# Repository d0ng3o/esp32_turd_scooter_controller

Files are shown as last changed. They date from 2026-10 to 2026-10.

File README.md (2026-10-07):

# Scooter control board

A standalone replacement control board for a **decommissioned Bird One #590AE**
shared e-scooter (the operator went bankrupt), built around a **Seeed XIAO
ESP32-C3**.

> ⚠️ **Safety-critical, experimental, unofficial.** This board controls a
> vehicle's motor, throttle, and braking behavior. It is provided **as-is, with
> no warranty**, is not certified by anyone, and is not affiliated with or
> endorsed by Bird. Build and ride at your own risk — read
> **[DISCLAIMER.md](DISCLAIMER.md)** first.

The project has two halves:

1. **Reverse-engineering** the scooter's one-wire bus between the original
   control board and the Lishui motor controller — captured and documented so
   the controller can be driven directly.
2. A **custom KiCad control board** that replaces the dead original: same
   harness connector, same bus protocol, plus throttle/brake sensing, pack
   voltage, a buzzer, an addressable status LED, an on-board IMU for
   wake-on-motion, and an OLED display.

## Repository layout

```
.
├── PROTOCOL.md                 the reverse-engineered one-wire bus protocol
├── captures/                   raw bus captures backing PROTOCOL.md
├── esp32-scooter-schematic.html  interactive overview of the board
│
├── scooter_master.py           drive the motor controller as the bus master
├── pi_sniff.py                 passive ride logger (Raspberry Pi, RX-only)
├── bus_experiment.py           scripted bring-up probes
├── bus_listen_poll.py          poll at 50 Hz and log non-echo bytes
├── bus_soak.py                 long idle soak to catch slow telemetry fields
├── install_logger.sh           one-shot Pi logger installer
├── pi-scooter-logger.service   systemd unit for the Pi logger
│
└── kicad/                      the hardware — see kicad/README.md
```

## The bus, briefly

Native **3.3 V open-drain half-duplex UART at 115200**. The control board is the
master: it polls the controller at 50 Hz with a colon-framed packet
(`':' TYPE LEN DATA[LEN] CHK CR LF`, `CHK` = XOR of the header+data) carrying the
throttle and light flags, and the controller answers with telemetry. Full frame
types, flags and field map are in **[PROTOCOL.md](PROTOCOL.md)**; it was all
confirmed on hardware (the PC drove the motor across the full throttle range).

## The hardware

The KiCad 10 design lives in **[kicad/](kicad/)** — see
[kicad/README.md](kicad/README.md) for the board overview,
[kicad/board/BOM.md](kicad/board/BOM.md) for the parts and full design
rationale, and [kicad/board/LAYOUT.md](kicad/board/LAYOUT.md) for the layout
playbook. The board is DRC-clean; bare boards and parts have been ordered.

## Status

- ✅ Bus protocol reverse-engineered and documented.
- ✅ Host/Pi tooling to drive and log the bus.
- ✅ Control board schematic + PCB complete, DRC-clean, ordered.
- ⬜ ESP32-C3 firmware — not in this repo yet.

## Note

The Python here is **host-side** tooling (PC / Raspberry Pi) used to
reverse-engineer and exercise the bus. It connects to the scooter via a USB
serial adapter (`scooter_master.py`, bench scripts) or a Pi UART (`pi_sniff.py`).
The firmware that will run on the XIAO itself is separate and not committed yet.

## License

This project is **free/libre and strong-copyleft** — multi-licensed by component,
with each layer under a **share-alike** license. Anyone who copies, modifies, or
builds on it **must release their version under the same license** (no closed or
proprietary forks):

| Component | Files | License |
|---|---|---|
| Code / firmware / scripts | `*.py`, `*.sh`, `*.service` | **GPL-3.0-or-later** — [`LICENSE`](LICENSE) |
| Hardware design (original) | `kicad/board/`, original symbols/footprints | **CERN-OHL-S-2.0** — [`LICENSE-HARDWARE.txt`](LICENSE-HARDWARE.txt) |
| Documentation | `*.md`, BOMs, `esp32-scooter-schematic.html` | **CC-BY-SA-4.0** — [`LICENSE-DOCS.txt`](LICENSE-DOCS.txt) |

Copyright 2026 Taavi Laadung.

**Exception:** the vendor-sourced symbols, footprints, and 3D models under
`kicad/lcsc/` are **not** covered by the above and keep their original
LCSC/EasyEDA/manufacturer terms — see [`kicad/lcsc/README.md`](kicad/lcsc/README.md).

**CERN-OHL-S v2 notice (hardware):** *Copyright 2026 Taavi Laadung. This source
describes Open Hardware and is licensed under the CERN-OHL-S v2. You may
redistribute and modify this source and make products using it under the terms of
the CERN-OHL-S v2 (https://ohwr.org/cern_ohl_s_v2.txt). This source is distributed
WITHOUT ANY EXPRESS OR IMPLIED WARRANTY, INCLUDING OF MERCHANTABILITY,
SATISFACTORY QUALITY AND FITNESS FOR A PARTICULAR PURPOSE. Please see the
CERN-OHL-S v2 for applicable conditions. Source location:*
`https://github.com/d0ng3o/esp32_turd_scooter_controller` *(CERN-OHL-S requires the
source location to be conveyed and, where practicable, kept visible on the product
itself).*

## Disclaimer

See **[DISCLAIMER.md](DISCLAIMER.md)** for the full safety warning and the
"no affiliation" / reverse-engineering notices. In short: this is an
experimental, uncertified board that controls a vehicle — **build and ride at
your own risk**, and check your local road-traffic laws before using it.

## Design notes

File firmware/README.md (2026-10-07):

# Scooter controller firmware (ESP-IDF)



Firmware for the on-board **Seeed XIAO ESP32-C3 (U3)**. It reads the rider's
throttle and brake, drives the Lishui motor controller over the scooter's
one-wire bus (see [`../PROTOCOL.md`](../PROTOCOL.md)), and enforces the safety
interlocks. Built with **ESP-IDF v5.2+**.

> ⚠️ Safety-critical. Read [`../DISCLAIMER.md`](../DISCLAIMER.md). The default
> state is always **throttle 0**; any lost bus link or engaged brake forces it.

## Status

| Area | State |
|---|---|
| One-wire open-drain UART bus (colon protocol, echo-filtered, 50 Hz poll + status decode) | ✅ |
| Throttle/brake ADC, filtering, mapping | ✅ (placeholder calibration) |
| Ride state machine + failsafes (brake→0, link-loss, lock) | ✅ |
| Kick-to-start | enforced by the motor controller (PROTOCOL.md §6.2) — not duplicated in firmware |
| Ride-feel shaping (throttle cap, curve, soft-start) | ✅ |
| NVS config store (all tunables, web-UI-ready) | ✅ |
| Configurable lights (headlight auto/on/off/manual, experimental brake strobe) | ✅ |
| Gestures: unlock (brake+triple-blip) / config-mode (brake+full 20 s) | ✅ |
| Lock/security: boots locked, auto-lock, motion alarm | ✅ |
| IMU (LSM6DS3TR-C) wake-on-motion + idle keep-alive | ✅ |
| Deep sleep to conserve the pack (two-stage idle; lights cleared before sleep) | ✅ |
| WiFi config portal + web UI + OTA (brake+20 s gesture) | ✅ |
| Pack-voltage sensing (ADC2, WiFi-gated) | ✅ |
| Guided throttle/brake calibration (web UI) | ✅ |
| OLED telemetry (SSD1309, LVGL) | ✅ |

**Feature-complete** against the plan. Remaining work is hardware validation
(the open-drain single-wire UART and the IMU register sequence want a scope).

## Layout

```
firmware/
├── CMakeLists.txt, sdkconfig.defaults, partitions.csv   # project + dual-OTA flash map
└── main/
    ├── board.h        pin map + tunables (edit here)
    ├── protocol.[ch]  frame build/decode + XOR checksum (ports PROTOCOL.md)
    ├── bus.[ch]       open-drain UART, echo filter, poll loop, telemetry
    ├── inputs.[ch]    throttle/brake ADC + mapping
    ├── control.[ch]   ride state machine + safety interlocks
    ├── buzzer.[ch]    LEDC tones
    ├── status_led.[ch] WS2812 (led_strip)
    └── app_main.c     init + real-time ride loop
```

## Building (manual, from scratch)

Built and verified with **ESP-IDF v5.4** (v5.2+ should work). The only external
dependency is the managed component `espressif/led_strip`, fetched automatically
on the first build.

### 1. Install ESP-IDF (one-time)

**Windows** (PowerShell):
```powershell
git clone -b release/v5.4 --recursive https://github.com/espressif/esp-idf.git "$env:USERPROFILE\esp\esp-idf"
& "$env:USERPROFILE\esp\esp-idf\install.ps1" esp32c3
```

**Linux / macOS**:
```bash
git clone -b release/v5.4 --recursive https://github.com/espressif/esp-idf.git ~/esp/esp-idf
~/esp/esp-idf/install.sh esp32c3
```

(Alternatively use the official VS Code **ESP-IDF extension** or the Windows
installer — both wrap the same steps.)

### 2. Export the environment (each new shell)

This sets `IDF_PATH` and puts `idf.py` + the RISC-V toolchain on `PATH`. It does
**not** persist, so run it in every new terminal:

- **Windows** (PowerShell): `. "$env:USERPROFILE\esp\esp-idf\export.ps1"`
- **Linux / macOS**: `. ~/esp/esp-idf/export.sh`

### 3. Build

```bash
cd firmware
idf.py set-target esp32c3     # first time only (creates sdkconfig from sdkconfig.defaults)
idf.py build
```

The first build compiles all of ESP-IDF (several minutes); later builds are
incremental. Output: `build/turd_scooter_fw.bin` (~243 KB).

One-liner for a fresh Windows shell:
```powershell
. "$env:USERPROFILE\esp\esp-idf\export.ps1"; cd firmware; idf.py build
```

### 4. Flash & monitor

Connect the XIAO over USB-C (native USB-Serial-JTAG), then:
```bash
idf.py -p <PORT> flash monitor      # e.g. -p COM7 (Windows) or -p /dev/ttyACM0 (Linux)
```
Exit the monitor with **Ctrl-]**. Console/log runs on USB-Serial-JTAG, so
**UART1 (GPIO20/21) stays free for the motor bus** and flashing never fights the
bus link.

### Housekeeping

- `idf.py fullclean` — wipe `build/`.
- `idf.py menuconfig` — edit settings interactively (defaults come from
  `sdkconfig.defaults`; the generated `sdkconfig` and `build/` are git-ignored).
- `idf.py size` — flash/RAM usage breakdown.

## Pin map (XIAO silk → GPIO)

| Silk | GPIO | Function |
|---|---|---|
| D1 | 3 | brake (ADC1_CH3) |
| D2 | 4 | throttle (ADC1_CH4) |
| D6 | 21 | bus TX (open-drain) |
| D7 | 20 | bus RX (tied to D6) |
| D8 | 8 | WS2812 status LED |
| D9 | 9 | buzzer |

(D0 IMU-INT, D3 pack sense, D4/D5 I²C, D10 expansion are wired but used by later phases.)

## Bench testing (before the scooter arrives)

1. **Echo filter / loopback.** Jumper D6↔D7 (they're tied on the real board
   anyway). On boot the LED is red (no link) and you get the fault chirp — the
   poll stream transmits and its echo is stripped, so no frames mis-parse.
2. **Fake controller.** Drive the bus from a PC/USB-TTL running
   [`../scooter_master.py`](../scooter_master.py) as the *slave side*, or replay a
   `../captures/` status frame, and confirm the monitor shows the link going
   green and telemetry decoding (cross-check fields against `../pi_sniff.py`).
3. **Throttle/brake.** A pot on D2 (and D1) → watch the state machine: stopped =
   IDLE (blue), and with a simulated moving `speed>0` from the fake controller,
   release-then-apply throttle → RIDING (green); brake → BRAKING (amber), throttle 0.

## Configuration

Every tunable lives in the NVS config store and can be changed two ways, with no
rebuild — over the USB serial console, or the WiFi web portal. See the full
hardware bring-up steps in [BRINGUP.md](BRINGUP.md).

### USB serial console

Open the USB-Serial-JTAG port (`idf.py -p <PORT> monitor`, or any 115200 serial
terminal) and type at the `scooter>` prompt:

| Command | Description |
|---|---|
| `help` | list commands |
| `get` | print the full config as JSON |
| `set <key> <value>` | change one setting + save to NVS (e.g. `set throttle_cap 220`, `set headlight_mode 1`, `set ap_ssid myscooter`) |
| `status` | live telemetry: link / lock / speed / SoC / current / pack V |
| `cal start` … `cal apply` | guided calibration (`cal show` to watch, `cal cancel` to abort) |
| `wifi on` / `wifi off` | start/stop the config + OTA WiFi portal |
| `defaults` | reset config to defaults |
| `reboot` | restart |

Keys are the JSON field names printed by `get`.

### WiFi web portal (+ OTA)

Hold **brake + full throttle for 20 s** while stopped to bring up the SoftAP
(`ap_ssid`, default `turd-scooter`) at **192.168.4.1**. The page offers the same
settings as a form, a live status readout, the guided calibration, and **OTA**
firmware upload. It auto-exits after `config_timeout_s`.

### Calibration

Throttle/brake endpoints ship as placeholders in `board.h` until the real harness
is on the bench. Run `cal start` (console or web) → move both controls through
their full travel → `cal apply` to capture and save the real min/max.

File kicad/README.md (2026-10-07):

# XIAO ESP32-C3 scooter control board — KiCad

Replacement control board for a decommissioned **Bird One #590AE** e-scooter.
A **Seeed XIAO ESP32-C3** reads the throttle and brake, talks to the Lishui
motor controller over the scooter's native **one-wire 3.3 V open-drain UART**
(115200), senses pack voltage, drives a buzzer and an addressable status LED,
carries an on-board IMU for wake-on-motion, and shows telemetry on an
enclosure-mounted OLED.

Designed in **KiCad 10**.

## Layout

```
kicad/
├── board/
│   ├── scooter_board.kicad_pro   project
│   ├── scooter_board.kicad_sch   schematic  ─┐ source of truth
│   ├── scooter_board.kicad_pcb   PCB         ─┘
│   ├── BOM.md                    bill of materials + full design rationale
│   ├── LAYOUT.md                 placement/routing playbook
│   ├── fp-lib-table              points at ../lcsc (the project footprint lib)
│   └── fabrication-toolkit-options.json
├── lcsc/                         project-local parts (LCSC-sourced)
│   ├── scooter_lcsc.kicad_sym    symbols
│   ├── scooter_lcsc.pretty/      footprints (6, all used by the board)
│   └── scooter_lcsc.3dshapes/    3D models for those footprints
├── lcsc_order_bom.csv            LCSC BOM-Tool upload (5 boards, no spares)
└── poop_logo.svg                 silkscreen art
```

Open `board/scooter_board.kicad_pro` in KiCad 10. The project footprint/symbol
libraries under `lcsc/` are referenced project-relative (`${KIPRJMOD}`), so the
board opens with all parts and 3D models intact — nothing to install.

## The board at a glance

- **2-layer, ~61 × 61 mm**, GND pour both sides with stitching vias.
- **MCU:** XIAO ESP32-C3 (U3), direct-solder castellated footprint.
- **Bus:** native 3.3 V open-drain half-duplex UART — D6 (OD TX) + D7 (RX) tied,
  100 Ω series (R6) to the harness, SMF3.3A TVS (D4) at the port. **No buffer IC.**
- **Analog:** throttle / brake / pack dividers → ADCs, 3.3 V zener clamps (D1–D3).
  Pack sense is on ADC2 (WiFi-coexistence caveat — see BOM.md).
- **IMU:** on-board LSM6DS3TR-C (U2, LGA-14), I²C, INT1 → D0 for deep-sleep
  wake-on-motion.
- **Outputs:** passive buzzer (BZ1 + Q1 low-side), WS2812B status LED (LED1, +5 V).
- **Connectors:** Amphenol 98424-F52-12ALF harness (J3), JST-GH to the off-board
  OLED (J4), 1×7 expansion header (J6, carries raw PACK_41V on pin 7).

Full part list, LCSC numbers, GPIO map, Amphenol pinout and the reasoning behind
every choice are in **[board/BOM.md](board/BOM.md)**. Layout/placement guidance is
in **[board/LAYOUT.md](board/LAYOUT.md)**.

## Ordering

Every placed part carries an `LCSC` field, so the project is the source of truth
for sourcing. Two paths:

- **Bare boards + self-assembly (current plan):** export Gerbers/drill from the
  PCB editor and order the bare board; order the parts from LCSC by uploading
  `lcsc_order_bom.csv` to the [LCSC BOM Tool](https://www.lcsc.com/bom).
- **JLC assembly:** generate a BOM + CPL with the Fabrication Toolkit plugin
  (part field = `LCSC`). Note U2 (LGA) and J3 (2 mm SMD) need hot-air/assembly.

Run **DRC** before ordering. The board is DRC-clean as committed.

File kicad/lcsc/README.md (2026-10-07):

# Project parts library (vendor-sourced)

These symbols, footprints, and 3D models were imported from **LCSC / EasyEDA** and
the component manufacturers using [`easyeda2kicad`](https://github.com/uPesy/easyeda2kicad.py),
then adjusted for this board (e.g. the XIAO and Amphenol footprints).

## Licensing

Unlike the rest of this repository, the contents of this `lcsc/` directory are
**not original work** and are **not** covered by the project's CERN-OHL-S /
GPL-3.0 / CC-BY-SA licenses. They remain subject to the terms of their original
sources (LCSC / EasyEDA and the respective component manufacturers). They are
included only for convenience, so the board opens with parts and 3D bodies intact.

If you would rather not redistribute vendor models, delete the `.step` / `.wrl`
files (and, if you like, the whole library) and regenerate them from the LCSC part
numbers listed in [`../board/BOM.md`](../board/BOM.md):

```
python -m easyeda2kicad --full --lcsc_id C<number> --output scooter_lcsc
```

## Contents

- `scooter_lcsc.kicad_sym` — schematic symbols
- `scooter_lcsc.pretty/` — footprints (6, all used by the board)
- `scooter_lcsc.3dshapes/` — 3D models (`.step` + `.wrl`) for those footprints

The board also uses a few footprints from KiCad's **standard** libraries (JST-GH,
pin header) — those ship with KiCad and are not duplicated here.

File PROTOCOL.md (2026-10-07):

# Scooter One-Wire Bus Protocol

Reverse-engineered 2026-09-11 from a decommissioned shared e-scooter
(manufacturer bankrupt). This document is the reference for writing software or
firmware that replaces the original **control board** and drives the **motor
controller** directly.

- **Master** = control board (sends polls, throttle, light commands, queries)
- **Slave** = motor controller (answers polls with telemetry, holds the motor)

Everything here was confirmed on hardware: the PC drove the motor across the
full throttle range through this protocol.

---

## 1. Physical layer

| Property | Value |
|---|---|
| Bus | Single wire, half-duplex, shared by both ends |
| Idle level | High, pulled up by the controller through ~740 Ω |
| Logic | 3.3 V TTL |
| UART | 115200 baud, 8 data bits, no parity, 1 stop (8N1)  |
| Direction | Both ends transmit on the same wire; no flow ctrl  |

Because it is one wire, **every byte you transmit is also received back as an
echo.** Filter your own echo before parsing replies.

### Wiring a USB-TTL adapter as master

```
  adapter GND ------------------------------ scooter GND
  adapter RX  ------------------------------ data line        (read direct)
  adapter TX  ----[ 100 Ω ]----------------- data line        (drive through R)
```

The controller's ~740 Ω pull-up is strong. A diode-OR from TX only reaches
~1.3 V low and the controller ignores it; 1 kΩ in series gives ~1.9 V, also
ignored. **100 Ω gives a valid low and works.** The resistor limits contention
current (~30 mA for the ~2 ms the controller is replying) but leaves ~15 % of
frames colliding. For a permanent build use a real open-drain driver
(74HC07 / 74LVC07, or an FTDI adapter with TX inverted in EEPROM plus one
MOSFET) so there is no contention.

**Disconnect the original control board from the data line before driving the
bus. Never run two masters at once.**

---

## 2. Frame format (both directions)

The steady-state protocol is a colon-delimited ASCII-framed binary protocol.

```
  +------+------+------+=================+------+------+------+
  | 0x3A | TYPE | LEN  |   DATA[LEN]     | CHK  | 0x0D | 0x0A |
  +------+------+------+=================+------+------+------+
    ':'   type   len      payload          xor    CR     LF

  CHK = XOR of every byte from 0x3A through the last DATA byte (inclusive).
        i.e. XOR of  ':', TYPE, LEN, DATA[0..LEN-1].
  Total frame length = LEN + 6.
```

**Request / reply pairing:** the reply TYPE equals the request TYPE minus
`0x0A`. Poll `0x1A` → status `0x10`; serial `0x1B` → `0x11`; firmware
`0x1D` → `0x13`; `0x1E` → `0x14`.

### Checksum reference (C)

```c
uint8_t xor_chk(uint8_t type, const uint8_t *data, uint8_t len) {
    uint8_t c = 0x3A ^ type ^ len;
    for (uint8_t i = 0; i < len; i++) c ^= data[i];
    return c;
}
```

---

## 3. Master → Slave (control board → motor controller)

### 3.1 Poll `0x1A` — sent continuously at 50 Hz (every 20 ms)

This is the heartbeat. It carries throttle and light state, and every 5th poll
also requests a status reply. **The slave only stays responsive while polled.**

```
  :  1A  02  TT  FF  CK  CR LF
           |   |
           |   +-- FF = flags byte (see below)
           +------ TT = throttle 0..255  (SPEED setpoint, not torque)

  DATA[0] = throttle
  DATA[1] = flags:
        bit 3  0x08  tail light   (master keeps this set at all times)
        bit 4  0x10  request status reply this poll (set on every 5th poll)
        bit 6  0x40  headlight    (master sets it while the wheel is moving)
```

Flag byte values seen on the wire: `0x08` (normal), `0x18` (status request),
`0x48` (headlight on), `0x58` (headlight + status request).

Examples (throttle 0, idle):

```
  status-request poll :  3A 1A 02 00 18 3A 0D 0A
  normal poll         :  3A 1A 02 00 08 2A 0D 0A
```

**Cadence pattern:** 4 normal polls then 1 status-request poll, repeating →
50 polls/s, 10 status replies/s.

### 3.2 Serial-number query `0x1B` — DATA = `"SN"` (0x53 0x4E)

```
  :  1B  02  53 4E  3E  CR LF        ->  slave replies 0x11
```
Answered any time.

### 3.3 Firmware query `0x1D` — DATA = `"FW"` (0x46 0x57)

```
  :  1D  02  46 57  <ck>  CR LF      ->  slave replies 0x13
```
**Only answered once, shortly after the controller's own power-up.** Later
queries get no reply.

### 3.4 Boot one-shots (original board sent these once at startup)

| TYPE | DATA | Reply | Notes |
|---|---|---|---|
| 0x1E | `20 10` | `0x14 20 10` | echoed back |
| 0x1F | `02 F4` | none | no observable effect |
| 0x20 | `00 87` | none | no observable effect |

These appear **unnecessary** to drive the motor; the controller runs on a bare
poll stream. Kept here for completeness.

---

## 4. Slave → Master (motor controller → control board)

### 4.1 Boot banner (unsolicited)

About 5 s after the controller powers up it sends, once:

```
  :  1D  "READY"  CR LF        =  3A 1D 52 45 41 44 59 0D 0A
```
(Note: this uses TYPE 0x1D as a one-off banner; it is not a reply to anything.)

### 4.2 Status `0x10` — 21-byte reply to a status-request poll, ~10 Hz

**This is the telemetry frame.** All 16-bit fields are **big-endian**.

```
  :  10  15  [ 21 data bytes ]  CK  CR LF

  offset  name          type    meaning
  ------  ------------  ------  --------------------------------------------
   0- 1   temp1         u16 BE  controller/FET TEMPERATURE (raw, scale TBD).
                                ~2960 cool; rises with ride time, holds at idle;
                                proven thermal by ride (corr 0.93 with time, not
                                current) + flat over a 1 h idle soak.
   2- 3   temp2         u16 BE  second TEMPERATURE (motor?). Same behaviour,
                                smaller rise (~2960->2980 over a ride).
   4- 5   current       u16 BE  battery current, 0.01 A units. 16-bit CONFIRMED:
                                reached ~20 A (b4=0x07) under real road load.
                                (idle ~0.03 A; ~20 A under load)
   6      (zero)        u8      always 0
   7      charge_A      u8      charge current, 0.01 A units (max 2.55 A)
                                (0 with charger unplugged; ~1.6 A CC tapering to
                                ~0.2 A CV while charging)
   8- 9   soc           u16 BE  state of charge, percent. b8 (high) always 0
                                in all data; effectively a single byte here.
  10      status_bit    u8      0 or 1; a status bit (meaning unresolved,
                                leans toward 'moving')
  11      (zero)        u8      always 0
  12      speed         u8      wheel speed reading (0..~156 powered cap;
                                seen up to 165 coasting/downhill past the limit)
  13      flag13        u8      constant 0x0E (unknown)
  14      (zero)        u8      always 0
  15-17   odometer      u24 BE  wheel-revolution counter (1 count ≈ 1 rev)
  18      state_flags   u8      motion-state bit flags (NOT constant):
                                0x01 base/ready (always set), +0x02 at standstill,
                                +0x04 at high speed near the limiter, 0x0b rare
  19      flag19        u8      constant 0x10 (unknown)
  20      margin        u8      load-sensitive voltage margin (NOT temperature).
                                ~105 idle-no-load; -33 when headlight on; sags
                                under motor load; slowly declines as pack depletes;
                                climbs while charging. Bus/back-EMF headroom.
```

Worked example (idle, off-charger):

```
  3A 10 15 0B A4 0B A4 00 04 00 00 00 64 00 00 00 0E 00 15 87 E7 01 10 63 56 0D 0A
           \___/ \___/ \___/ ^  ^  \___/ ^  ^  ^  ^  ^  \______/ ^  ^  ^  ck
            2980  2980  0.04A |  |   100 |  |  |  |  |   1411047  |  | 0x63
            v1    v2    curr  0 chg soc  1  0 spd 0e 0  odo rev   1 0x10
```

Both current fields (offsets 4-5 and 7) are in **0.01 A units**. Confirmed by
the charge field: it caps at 2.55 A as a single byte and read ~1.6 A tapering
to ~0.2 A on the charger, matching a ~2 A scooter charger; at a 0.1 A scale it
would imply an impossible ~16 A charger.

### 4.3 Serial reply `0x11` — DATA = ASCII identifiers

```
  "RF02P192150317 RF01L192001491"
```
Two space-separated IDs (controller and, likely, a second board).

### 4.4 Firmware reply `0x13` — DATA = ASCII version string

```
  "C2.12-P0.2/3.3-B2.0/2.2"
```
Sent only once after boot (see 3.3).

### 4.5 Echo reply `0x14` — DATA = `20 10`

Reply to `0x1E`.

---

## 5. Sequencing / timing

### 5.1 Cold boot (as the original board did it)

```
  t=0 s     controller powers up
  t≈+5 s    controller sends  : 1D "READY" CR LF
  t≈+16 s   board begins probing with legacy framings, unanswered:
              - Xiaomi M365  (header 55 AA, addr 0x20)
              - unknown      (header BE EF)
              - Ninebot ES   (header 5A A5, src 0x21/0x3E dst 0x20)
            board sends SN/FW queries and the 1E/1F/20 one-shots (once)
  then      board settles into the colon protocol: 50 Hz polls forever
```

The legacy-probe phase is the board hunting for a known controller before
falling back to this vendor's own colon protocol. **You do not need to
reproduce it.** A bare 50 Hz poll stream is accepted, including after the
controller has been running a while.

### 5.2 Steady state

```
  poll 20 ms apart, pattern:  N N N N S  N N N N S ...   (S = status request)
  → 50 polls/s, 10 status frames/s
  Reply latency: status frame arrives within ~1 poll of the request.
```

### 5.3 Robustness observed

- **Poll gap:** stop polling for seconds, resume — status resumes on the next
  status-request poll. No re-handshake, no watchdog reset seen.
- **Peer drop/reconnect:** the controller resumes replying within ~200 ms of
  hearing polls again. It does **not** re-run the boot banner or probes.
- **Single-frame glitches:** occasional lone status frames carry a garbled
  field but still pass the checksum. **Filter single-frame outliers** (e.g. the
  odometer jumping and snapping back) in your reader.

---

## 6. Control behavior (for the firmware author)

### 6.1 Throttle is a SPEED setpoint, linear

Measured map (free-spinning wheel, 222 mm, ~25 km/h limit):

```
  throttle:    76   102   127   153   178   204   229   255
  speed rdg:   54    68    82    97   111   126   140   156
  free-I(A):  0.4   0.5   0.6   0.8   0.8   0.9   1.1   1.1
```

(Free-spin battery current, 0.01 A units. Real riding load draws more.)

Fit: `speed ≈ 0.56 × throttle + 11`, saturating at 156 (the 25 km/h limiter)
at throttle 255. Because it is a speed target, a lightly loaded wheel holds a
steady speed rather than running away.

Speed reading → real speed: at reading 156 the wheel turns ~10 rev/s. With a
0.70 m circumference that is ~7 m/s ≈ **25 km/h**, so the speed byte is
≈ 0.16 km/h per count (hypothesis: tenths of mph).

Odometer: **1 count ≈ 1 wheel revolution ≈ 0.70 m.** Not persisted by the
controller alone — it reset to its session-start value after a power cycle, so
the original board likely wrote it back.

### 6.2 Kick-to-start (safety interlock)

The motor engages **only if both** are true:

1. the wheel is already turning (any low speed reading works), and
2. the throttle **rises from idle** *after* motion is established
   (~0.3 s of confirmed motion first).

Throttle applied while stationary, or applied before/at the instant of the
push, is ignored until you release and re-apply. Design your throttle logic to
release to 0 and re-assert once the wheel is moving.

### 6.3 Brake

The lever is analog on the scooter but the board sends **no brake field**.
Instead, when the brake crosses ~half travel the master forces the **throttle
byte to 0x00** for as long as it is held. Braking is therefore "command speed
0"; there is no separate brake signal to the controller and no brake-light
change on the bus (the tail light is simply always on via flag 0x08).

Replicate this: read your brake input and clamp the throttle byte to 0 above
threshold.

### 6.4 Headlight

Master sets poll flag **0x40** while the controller reports speed > 0, and
clears it ~0.5 s after the wheel stops. The tail light is the always-on
flag 0x08. Both are commands from master to slave.

**The controller latches the last commanded light state when polling stops.** It
does not auto-clear the lights when the poll stream ends — it holds whatever was
last sent. So a master that is about to stop polling (e.g. firmware entering
deep sleep) must first send a poll with the light flags **cleared** (no 0x08 /
0x40) to turn the lights off; otherwise they stay lit on the dormant controller.
On resuming polling, normal flags turn them back on.

### 6.5 Power / charger interlock

- The controller drives the motor **only with battery power present.** With the
  battery disconnected it can boot on charger standby but reports 0.00 A and will
  not drive.
- To **ride**, the charger must be **unplugged** (a connected charger did not
  block motion in normal operation, but after a full battery disconnect the unit
  would only boot with the charger in — a BMS quirk; unplug it once running).

---

## 7. Minimal master loop (pseudocode)

```
open serial: 115200 8N1, COM4
n = 0
every 20 ms:
    n += 1
    flags = 0x08
    if n % 5 == 0:      flags |= 0x10        # request status
    if wheel_moving:    flags |= 0x40        # headlight
    throttle = brake_active ? 0 : throttle_cmd
    send_frame(0x1A, [throttle, flags])

on receive, after stripping our own echo:
    parse frames ':' TYPE LEN DATA CHK CR LF
    verify CHK (XOR)
    if TYPE == 0x10 and LEN == 21:  decode_status(DATA)   # see §4.2
    if TYPE == 0x11:  serial string
    if TYPE == 0x13:  firmware string
```

A reference implementation is in `scooter_master.py` (interactive, with logging
and a wiring self-check). Raw and decoded captures are under `captures/` and
`logs/`.

---

## 8. Open items

| Item | Status |
|---|---|
| `temp1`/`temp2` scale | Confirmed temperatures; raw→°C needs a thermometer |
| `b20` margin scale | Load-sensitive voltage margin; scale unmapped |
| Raw pack voltage | NOT transmitted; only SoC is sent |
| `flag13` (0x0E), `flag19` (0x10) | Constant; meaning unknown |
| Speed-byte real-world unit  | ≈0.16 km/h/count (hypothesis, tenths of mph) |
| Boot one-shots 0x1F / 0x20  | No observed effect; likely unnecessary |
| Odometer persistence | Not saved by controller alone |

`temp1`/`temp2` are confirmed temperatures (ride isolates them from load); to
calibrate raw→°C, hold a thermometer on the controller/motor while logging.
Pack voltage is not on the bus, only SoC.

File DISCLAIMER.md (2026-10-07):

# Disclaimer

## Safety

This is an **experimental, unofficial, hobbyist** replacement control board for
an electric scooter. It directly controls a vehicle's **motor, throttle response,
and related behavior** — a safety-critical function.

- It is provided **AS IS, WITHOUT WARRANTY OF ANY KIND**, as stated in the
  project licenses.
- It has **not** been tested, certified, or approved by any manufacturer,
  regulator, or road-safety authority.
- Building, assembling, installing, and riding anything based on these files is
  **entirely at your own risk**. You are responsible for your own safety and the
  safety of others around you.
- A fault in the hardware, firmware, or assembly could cause **sudden
  acceleration, loss of braking assistance, fire, or other dangerous failures**.
- Modifying an e-scooter may void warranties, violate local vehicle/road-traffic
  regulations, and affect insurance. **Check your local laws** before using it on
  public roads, paths, or anywhere else.

If you are not able to evaluate and knowingly accept these risks yourself, **do
not build or use this project.**

## No affiliation

This is an independent project. It is **not affiliated with, authorized by, or
endorsed by Bird**, Lishui, Seeed Studio, or any other company whose products or
trademarks are referenced. All product names and trademarks are the property of
their respective owners and are used here only for factual, descriptive
(interoperability) purposes — i.e. to state what hardware this project is
compatible with.

## Reverse engineering

The bus protocol documented here was obtained by **observing signals on hardware
that was legally acquired**, for the purpose of **interoperability** (building a
compatible replacement). No software was decompiled and no technical protection
measure (DRM/encryption) was circumvented.

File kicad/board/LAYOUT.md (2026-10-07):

# Scooter control board — PCB layout notes

Things to remember when placing and routing `scooter_board.kicad_pcb`.
Schematic-level placement hints (decoupling caps, IMU_INT) are also written as
text notes on the sheet itself. This file is the broader layout playbook.

The board has **no regulator and no high-current path** (buzzer ~90 mA is the
peak load), so there are **no thermal concerns** — this is a signal-integrity
and mechanical layout, not a power layout.

---

## 1. The big one: XIAO antenna keep-out (matters for WiFi/BLE)

The XIAO ESP32-C3 has a **PCB chip antenna at the USB-C end** of the module.
The module sits on sockets *above* this carrier board, so **copper on the
carrier under/around the antenna will detune it** and wreck WiFi range — which
you need for the config/OTA mode.

- Leave a **ground/copper keep-out** on *all layers* under the antenna end of
  the XIAO (roughly the last ~10 mm at the USB-C side). No pour, no traces there.
- Orient the XIAO so its antenna end points **off the board edge / toward open
  space**, not into the middle of the ground pour or toward the Amphenol/harness.
- Keep the buzzer, WS2812 and bus traces away from the antenna zone too.

## 2. Ground & power

- Use a **solid ground pour/plane** (bottom layer is fine) as the reference —
  except the antenna keep-out above.
- **Bulk caps at their jobs:** C6 at the Amphenol **+5V entry**, C7 on the 3V3
  rail, C10 right at the buzzer (see §5).
- **Wide traces for the current-carrying rails:** +5V feeds the XIAO regulator,
  buzzer and WS2812 — give it a fat trace/pour from the Amphenol. +3V3 similar.
- One clean ground: tie the analog return (divider/ADC grounds) and the digital
  ground to the same plane; just keep the *buzzer's* pulsed return loop physically
  away from the analog area (see §5).

## 3. Analog (throttle / brake / pack ADCs)

These are the noise-sensitive nets — treat them gently.

- **Filter caps C1 (thr) / C2 (brk) / C3 (pack) go next to the XIAO ADC pins**,
  not next to the dividers — they buffer the ADC sample-and-hold, so they want to
  be at the pin end.
- Keep the ADC nodes (`THR_ADC`, `BRK_ADC`, `PACK_ADC`) **short and clear of the
  buzzer, WS2812 (`RGB_DIN`) and the bus** — these are ~30–50 kΩ-impedance lines
  and pick up noise easily.
- The clamp zeners **D1/D2/D3 sit on the ADC nodes** near the XIAO.
- ADC pin map (for silkscreen/sanity): **D1 = brake, D2 = throttle, D3 = pack**
  (pack is ADC2 — see BOM's WiFi note).

## 4. One-wire bus

- **Put the TVS (D4) right at the Amphenol bus pin (J3.8)** so it clamps ESD at
  the port, before the signal reaches R6 and the XIAO.
- R6 (100 Ω) sits between the XIAO D6/D7 tie-point and the bus.
- The bus is only 115 kbaud, so trace length isn't critical — but still keep it
  off the analog nets.

## 5. Buzzer (BZ1 + Q1 + C10) — keep the loop tight

The buzzer is the one **noisy switching load** (2.7 kHz pulses).

- Keep the current loop **BZ1 → Q1 (drain) → C10 → back to +5V** physically
  small, with short/fat traces. That contains the switching noise locally.
- Place this whole cluster **away from the analog section (§3)** and the IMU.
- BZ1 pads **2 & 4 are mechanical fixing legs** (no net) — solder them for
  mechanical strength, but they carry nothing.
- Q1 SOT-23: G=pad1, S=pad2, D=pad3.

## 6. IMU (U2, LSM6DS3TR-C, LGA-14)

- **Leadless LGA — needs hot-air/reflow or JLC assembly**, not a hand iron.
- **C8 (VDD) and C9 (VDDIO) go hard against U2's power pins** with short ground
  returns — this is standard MEMS decoupling and matters for stable readings.
- **`IMU_INT` route short and clear of BZ/RGB/bus edges** to avoid false wakes
  (it's a high-impedance wake line). R14's own position is non-critical.
- Orientation: any orientation wakes on motion, but if you ever use tilt/axes,
  note the chip's X/Y/Z on the silkscreen relative to the scooter.

## 7. WS2812 status LED (LED1)

- **Powered at +5 V** (not 3V3). **C11 (100 nF) hugs LED1's VDD/GND.**
- Place it where the light is actually **visible** through/near the enclosure.
- `RGB_DIN` from D8 — keep it away from the analog nets.

## 8. Connectors & mechanical

- **Amphenol J3** (2 mm SMD, C239063): the harness interface. Check pin-1 /
  orientation against the mating harness before routing. This is the mechanical
  anchor to the scooter — its position is dictated by the harness, place it first.
- **XIAO (U3):** now a **single official footprint** (Seeed XIAO ESP32-C3,
  C19189385) — the two rows are at the correct fixed 17 × 2.54 mm spacing by
  construction, so no manual row-spacing to get wrong. It's the **SMD/castellated
  direct-solder** footprint (module sits flat, drag-solder the edge pads); the
  battery/debug pads on the underside are unused. Leave the **USB-C end
  accessible** for flashing/recovery, and honor the antenna keep-out (§1).
  *(If you switch to a socketed/removable through-hole footprint later, the
  antenna keep-out and USB-access notes still apply.)*
- **OLED — now off-board (J4 = JST-GH right-angle):** the 72 × 43 mm module is
  no longer on this board (it mounts to the enclosure and connects via a JST-GH
  cable). J4 is just the small 1.25 mm right-angle connector — **place it near a
  board edge with the cable exit facing the screen**, and keep its I²C legs away
  from the motor bus. No more overhang to plan around — that space is freed.
- **J6 expansion (1×7):** carries **raw PACK_41V on pin 7** — keep that pin's
  copper away from the 3V3 pins (GND on pin 6 already buffers it); the expansion
  board is responsible for its own protection.

## 9. High-voltage clearance (the 41 V pack)

- `PACK_41V` appears at the Amphenol (J3.10), R7's top pad, and J6 pin 7. It's
  **low current** (µA through the 470 k divider) so no trace-width concern, but
  keep sane **clearance** (≥ ~0.5 mm, easy at these pitches) from the low-voltage
  nets. Don't run 41 V under the XIAO or the analog dividers.
- +5 V from the harness can carry real current (XIAO + buzzer + LED) — that's the
  rail to make wide, not the 41 V sense line.

## 10. Board outline (odd shape)

- You're drawing the outline to match the original scooter PCB. Overlay a photo/
  scan on a user layer (File → Import graphics, or a bitmap on a fab layer) and
  trace `Edge.Cuts` + mounting holes to it. Place J3 (Amphenol) and the mounting
  holes to the mechanical reference first, then everything else around them.

## 11. Before ordering — checklist

- Run **DRC** (clearances, unrouted, courtyard overlaps) → clean.
- Confirm **antenna keep-out** is honored on all layers.
- Confirm XIAO **row spacing** and **USB-C access**.
- Confirm Amphenol **orientation** vs the real harness.
- Generate a **JLCPCB BOM + CPL** (Fabrication Toolkit, part field = `LCSC`);
  remember U2 (LGA) and J3 (2 mm SMD) want assembly or hot-air, and J1/J2 sockets
  are your own mechanical choice (no LCSC # assigned).
- 3D-view check for the OLED overhang and any part collisions.

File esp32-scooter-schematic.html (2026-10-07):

Rev A · Bench Reference

# XIAO Scooter Control Board

Wiring for a Seeed XIAO ESP32-C3 that replaces the dead Bird 590 control board: it reads the rider's throttle and brake, drives the Lishui motor controller over the one-wire 115200 bus, and shows telemetry on an OLED.

MCU

XIAO ESP32-C3

Bus

1-wire · 115200 8N1

Logic

3.3 V

Sensors

5 V Hall

## System schematic

41 V pack +5 V +3.3 V analog signal 1-wire data bus I2C

## Detail · the two tricky parts

Halving divider. Two equal 10 k resistors cut the sensor to half, keeping a 5 V fault off the pin and the signal in the ADC's linear band. The 100 nF cap feeds the sample-and-hold. Draw ≈ 0.25 mA per channel — negligible.

Half-duplex, one wire. Idle: buffer is Hi-Z, the controller's ~740 Ω pull-up holds the line high. A low bit: the buffer sinks ≈ 4.5 mA and the line goes low — a clean sub-0.3 V that the controller reads. No added pull-up. RX hears your own echo; filter it in software.

## Pin map

XIAO pin | GPIO | Role | Connects to
D0 | GPIO2 | ADC1_CH2 in | Throttle divider mid-node (0–2.5 V)
D1 | GPIO3 | ADC1_CH3 in | Brake divider mid-node (0–2.5 V)
D4 | GPIO6 | I2C SDA | OLED SDA
D5 | GPIO7 | I2C SCL | OLED SCL
D6 | GPIO21 | UART TX | 74LVC07 input → bus
D7 | GPIO20 | UART RX | Bus via 330 Ω
5V | — | Power in | Buck 5 V (or controller 5 V)
3V3 | — | Power out | OLED VCC
GND | — | Ground | Common with scooter GND

ADC on ADC1 (GPIO0–4) only — ADC2 is unstable on the C3. GPIO numbers are the ESP32-C3's; D-numbers are the XIAO silkscreen.

## Bill of materials

Qty | Part | Value / spec | Purpose
1 | Seeed XIAO ESP32-C3 | — | The controller / dashboard brain
4 | Resistor | 10 kΩ ¼W | Throttle + brake dividers (2 each)
2 | Capacitor | 100 nF | ADC sample filter on each mid-node
1 | 74LVC07A | hex open-drain | Bus TX driver (or 1× 2N7002 + TX invert)
2 | Resistor | 330 Ω | Series protection on RX / bus tap
1 | OLED SSD1306 | 128×64 I2C | Telemetry display
1 | Buck converter | 41 V → 5 V | Power (or tap controller's 5 V rail)
1 | Clamp diode (opt.) | BAT54 / 3.3 V zener | Transient protection on RX

## Build notes

### Power: two ways in

Cleanest is a 41 V→5 V buck off the pack into the XIAO's 5 V pin — it doesn't load the controller and leaves room for a standby cutoff later. Or tap the controller's own 5 V rail if it can spare ~100 mA for MCU + OLED + sensors. Tie all grounds together.

### Sensors need 5 V

The Hall throttle and brake are 5 V parts. Feed their VCC from the 5 V rail, run the signal back through the dividers. Calibrate idle and full-scale in software and average a few samples — the C3 ADC is a touch noisy.

### Brake logic lives in firmware

The controller has no brake field. Mirror the stock board: when the brake ADC crosses ~half travel, force the throttle byte in the 0x1A poll to 0x00. Braking is "command speed zero", nothing more on the wire.

### Why not just a bare divider on TX?

The bus is bidirectional. TX must release the line so the controller can drive its replies — that's what open-drain gives you. A plain divider or a diode can't reach a low the controller reads against its stiff 740 Ω pull-up; the 100 Ω hack proved that on the bench.

Bird 590 · Lishui LSW6G-RF-FOC · colon protocol 115200 8N1 — see PROTOCOL.md for the frame + field map

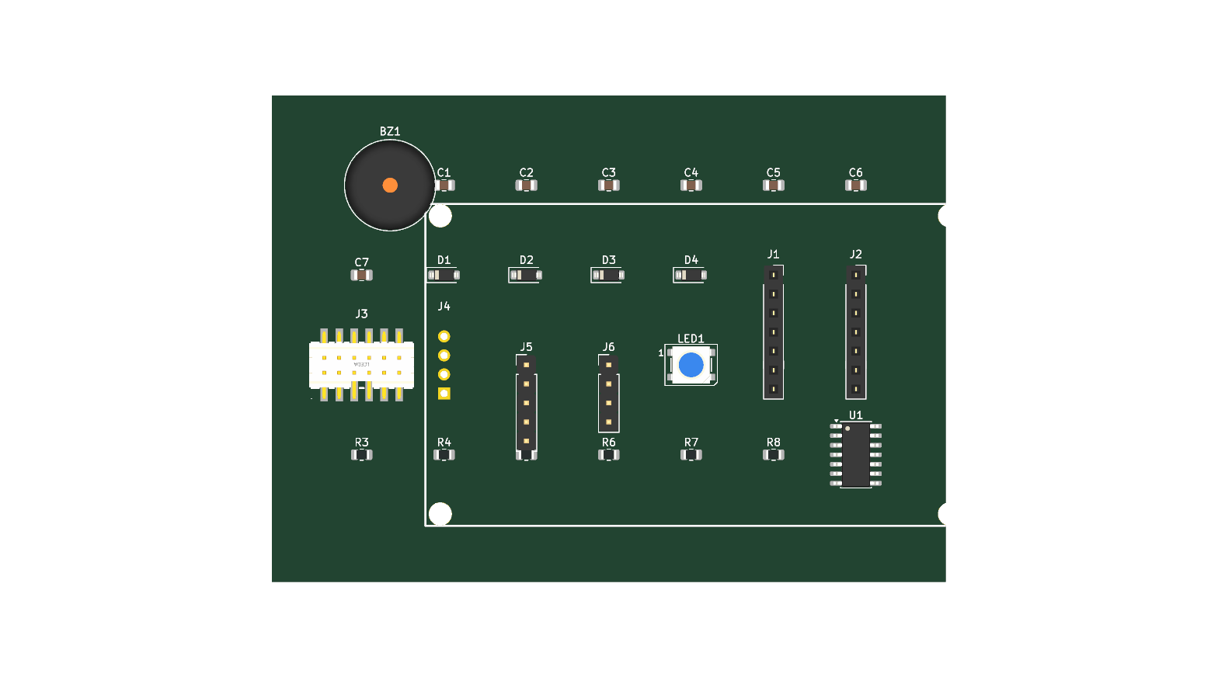
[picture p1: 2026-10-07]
kicad/board/scooter_board_render_top.png

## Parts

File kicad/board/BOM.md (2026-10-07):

# Scooter control board — BOM (LCSC / JLCPCB oriented)

Hand-solderable board: 0805 passives, SOD-123 zeners/TVS, SOT-23 MOSFET,
through-hole headers, one low-profile SMD buzzer, one 2 mm SMD Amphenol
connector. The bus is native 3.3 V open-drain UART off the XIAO (no buffer IC).
Modules (XIAO, OLED) plug into headers; IMU is on-board.

| Ref(s) | Qty | Part | Package | LCSC | Notes |
|---|-----|---|---|---|---|
| J3 | 1 | Amphenol 98424-F52-12ALF | 2×6, 2.0 mm SMD | **C239063** | confirmed; mates the scooter harness |
| R1–R4 | 4 | 100 kΩ 1% | 0805 | **C17407** | throttle + brake dividers (100k halves the 5 V signal at ~25 µA/divider). Basic |
| R6 | 1 | 100 Ω 1% | 0805 | **C17408** | bus series/protection (D6+D7 tied → R6 → bus). 100 Ω keeps the driven LOW clean (~0.4 V). Basic |
| R7 | 1 | 470 kΩ 1% | 0805 | **C17709** | pack divider top. Basic |
| R8 | 1 | 33 kΩ 1% | 0805 | **C17633** | pack divider bottom (was 30k → 33k to stay Basic; 470k/33k = 2.75 V @ 42 V). Basic |
| R9 | 1 | 1 kΩ 1% | 0805 | **C17513** | buzzer MOSFET gate series (D9→gate). Basic |
| R10 | 1 | 1 MΩ 1% | 0805 | **C17514** | buzzer MOSFET gate pulldown. **1M (not 100k): D9=GPIO9 is an ESP32-C3 boot-strap pin; a 100k pulldown drags it to ~2.3 V < V_IH at reset → download mode. 1M loads it lightly so it stays high.** Basic |
| R11, R12 | 2 | 4.7 kΩ 1% | 0805 | **C17673** | I²C pull-ups on SDA/SCL to +3V3. **Keep populated** — the on-board IMU (U2) is a bare chip with none, and the XIAO's internal pull-ups (~45k) are too weak. If your OLED module also has pull-ups they end up in parallel (~2.4k), still fine. Basic |
| R13 | 1 | 100 kΩ 1% | 0805 | **C17407** | pull-up on RGB_DIN (D8) to +3V3 — D8=GPIO8 is a boot-strap pin that would otherwise float at reset. Basic |
| R14 | 1 | 100 kΩ 1% | 0805 | **C17407** | pull-up on IMU_INT (D0/GPIO2) to +3V3 — holds the strap pin high at boot while the IMU is still initializing (INT1 hi-Z). See the IMU wake-on-motion note below. Basic |
| C1–C5, C8, C9 | 7 | 100 nF 50 V X7R | 0805 | **C49678** | ADC filters + decoupling (C8/C9 = IMU VDD/VDDIO). Basic |
| C11 | 1 | 100 nF 50 V X7R | 0805 | **C49678** | WS2812 local decoupling (+5V→GND at LED1, datasheet-recommended). Basic |
| C6, C7, C10 | 3 | 10 µF 16 V X5R | 0805 | **C1713** | C6 = 5 V bulk at Amphenol entry, C7 = 3V3 bulk, C10 = local buzzer decoupling (+5V→GND at BZ1, keeps the 2.7 kHz switching loop local). 16 V = >3× derating on the 5 V rail. Samsung CL21A106KOQNNNE, MOQ 20 |
| D1–D3 | 3 | 3.3 V Zener BZT52C3V3 | SOD-123 | **C173413** | clamp on throttle/brake/pack ADCs. Extended (no Basic in SOD-123) |
| D4 | 1 | SMF3.3A TVS (3.3 V, unidir.) | SOD-123 | **C2917875** | bus ESD/surge clamp (cathode→bus, anode→GND). ZHIDE SMF3.3A, MOQ 5 (was C283866, out of stock). Extended |
| Q1 | 1 | 2N7002 N-MOSFET (CJ) | SOT-23 | **C8545** | low-side buzzer switch (G/S/D = pad 1/2/3). Basic |
| LED1 | 1 | WS2812B-B/W (addressable RGB) | PLCC-4 5050 | **C114586** | status LED. **Powered at +5 V** (datasheet VDD 3.7–5.3 V, so 3.3 V is out of spec). The B/W variant's DIN V_IH is a fixed 2.7 V, so the ESP32's 3.3 V drives it directly — **no level shifter needed.** Extended |
| BZ1 | 1 | HYG-8503A-5027 buzzer, 5 V, passive | 8.5×8.5 mm SMD, **3.0 mm H** | **C18623826** | low-side driven by Q1; +→+5V (pad1), −→drain (pad3), pads 2/4 = fixing legs (NC). Firmware drives D9 with a ~2.7 kHz square wave. No flyback (per datasheet driving circuit). Extended |
| U2 | 1 | LSM6DS3TR-C IMU (accel + gyro) | LGA-14 2.5×3 mm | **C967633** | on-board IMU, I²C (0x6A), wake-on-motion INT1→D0. CS→3V3, SA0/SDx/SCx→GND. **Leadless — needs hot air/reflow or JLC assembly.** Extended |
| J4 | 1 | JST-GH 4-pin, right-angle SMD (SM04B-GHS-TB) | 1.25 mm, locking | **C189895** | off-board OLED link (I²C). Pinout **1=GND, 2=+3V3, 3=SCL, 4=SDA**. Locking latch = good for vibration. OLED now mounts to the enclosure, wired here via a GH cable. |
| U3 | 1 | Seeed XIAO ESP32-C3 module | LCC-14 (castellated, SMD) | **C19189385** | the MCU. **Official footprint = SMD/castellated direct-solder** (module reflows/drag-solders flat; no sockets). 14 edge pads (D0–D10, 3V3, GND, 5V) + battery/debug pads (unused). ⚠️ if you want it **socketed/removable**, ask for a through-hole footprint at the same 17×2.54 mm spacing instead. |
| J6 | 1 | 1×7 male header 2.54 mm | TH | **C2337** | expansion: D10, SDA, SCL, +5V, +3V3, GND, **PACK_41V** (pin 7, raw pack — GND on pin 6 buffers it from the 3V3 pins; expansion board handles its own protection). 1×40 breakaway, snap to length |

Off-board / sourced separately:
- **XIAO ESP32-C3** (Seeed) — now soldered as U3 (on-board), not a plug-in.
- **OLED 2.42″ SSD1309 128×64 I2C** (HS, on LCSC): white **C7466001** or blue **C7466000**. 4-pin TH 2.54 mm, pinout GND/VCC/SCL/SDA. **Now enclosure-mounted**, connected to J4 via a JST-GH cable — put a matching GH connector on the OLED's little adapter board, same pin order.
- **GH cable + OLED-side connector:** JST-GH 4-pin cable = **GHR-04V-S** housing (×2, one per end) + **SSHL-002T-P0.2** crimp contacts, or a pre-made 4-pin GH-to-GH cable. Wire it **straight-through 1:1** (GND/3V3/SCL/SDA). Keep it short (≲20 cm) for clean I²C; if long/flaky, drop R11/R12 to ~2.2 kΩ or run I²C at 100 kHz.

(The IMU is now the on-board **U2 LSM6DS3TR-C** chip — no longer a plug-in module.)

## Ordering / LCSC linkage

Every placed component now carries an **`LCSC`** schematic field with the part
number above, so the KiCad project itself is the source of truth (not just this
file). Generate a JLCPCB-ready BOM + placement file with the **Fabrication
Toolkit** plugin (bennymeg) or **File → Export → BOM** — point the tool's part
field at `LCSC`. J1/J2 are intentionally blank (your socket/mounting choice).

3D models: Q1, BZ1 and the Amphenol link portable `${KIPRJMOD}`-relative `.wrl`
models. The OLED (C7466001) has no vendor 3D model on EasyEDA, so J4 shows no
body in the 3D viewer — cosmetic only.

## Net / GPIO map

- **D0 IMU INT (deep-sleep wake) · D1 brake ADC · D2 throttle ADC · D3 pack ADC**
  - *(IMU_INT is on D0/GPIO2 — a boot-strap pin — deliberately: it's a clean digital line that a pull-up (R14) holds high at boot with no coupling to any rail. Pack was moved OFF the strap pin to D3/GPIO5, so its divider goes straight to GND with no rail coupling. See the two notes below.)*
  - *(pack is now on **ADC2** (D3/GPIO5). ADC2 on the C3 has a WiFi-coexistence caveat — reads can be blocked while the WiFi driver calibrates — but pack V is a secondary/coarse, retryable reading (bus SoC is primary), so it's fine. Throttle/brake stay on ADC1 (D2/D1).)*
  - *(all 3 strap pins are handled: D0=GPIO2 held high by R14; D8=GPIO8 by R13; D9=GPIO9 by R10=1M.)*
  - *(firmware ADC channels: brake = A1/D1, throttle = A2/D2, pack = A3/D3.)*

## IMU wake-on-motion + boot-strap (D0/GPIO2)

The IMU (U2) INT1 drives D0/GPIO2, which is both a **deep-sleep wake pin** (GPIO0–5 can wake the C3) and a **boot-strap pin**. Configure INT1 as **open-drain, active-low**, with **R14 (100 k)** pulling the line to +3V3:

- **Deep-sleep idle (no motion):** INT1 hi-Z → R14 holds the line high → *near-zero* sleep current (nothing conducts). Wake is armed on the LOW level.
- **Motion → wake:** INT1 pulls low → wakes the XIAO. On wake, firmware reads the IMU status reg to clear/deassert INT1.
- **Cold power-on:** the IMU takes ~15 ms to boot (INT1 hi-Z) while the ESP32 samples straps within ~1–3 ms → R14 holds D0 high → strap-safe.
- **At the wake instant** D0 is momentarily low, but only **GPIO9** decides run-app vs. download boot (it's untouched, internal pull-up), so the chip always boots the app; a low D0 at most affects JTAG (unused).

Firmware: `CTRL3_C` → PP_OD=1 (open-drain), H_LACTIVE=1 (active-low); route wake-up/activity IRQ to INT1; `esp_deep_sleep_enable_gpio_wakeup(BIT(2), ESP_GPIO_WAKEUP_GPIO_LOW)`. Bench-verify: sleep → tap → wakes & runs app, ~10×.

## Pack ADC (ADC2) vs. WiFi — firmware constraint

Pack sense is on **D3/GPIO5 = ADC2**. On the ESP32-C3 the WiFi driver owns ADC2 while it's running, so `adc2_get_raw()` fails/blocks **whenever WiFi is up** (not intermittent — unavailable while up, fully available while down). This is fine because the two are mutually exclusive by design:

- **Riding (normal): WiFi off** → pack ADC2 reads normally.
- **Config / OTA mode (entered by a throttle+brake gesture): WiFi on** → ADC2 blocked, but pack voltage isn't needed then, and the **controller's SoC over the bus is still available** (bus is unaffected by WiFi).

Key point: the **gesture trigger and drive-by-wire are on ADC1 (throttle D2 / brake D1)**, which WiFi never touches — so entering/exiting config mode is always reliable regardless of radio state.

Firmware rule: **read ADC2 (pack) only while the radio is stopped**; when WiFi is up, skip the pack read and fall back to the cached value or bus SoC. On exiting config mode, stop WiFi → ADC2 is available again immediately.

⚠️ If you ever run a **continuous radio during riding** (e.g. a BLE telemetry app), the radio is up while you want live pack voltage. BLE's ADC2 impact is less clear-cut than WiFi's — so in that case, use bus SoC for battery display while the radio is active and only sample ADC2 pack when it's idle. No hardware change either way.

- D4/D5 I2C (OLED + IMU) · **D6/D7 one-wire bus — tied together, D6 = open-drain TX, D7 = RX, through R6 (100 Ω) to the bus; SMF3.3A TVS on the bus**
- D8 WS2812 data · D9 buzzer · D10 expansion (J6 also carries I²C, +5V, +3V3, GND and raw PACK_41V)
- Unlock = brake + throttle gesture in firmware (no button)
- **Bus is native 3.3 V open-drain half-duplex UART** — no level shifter/buffer. Firmware: set the D6 UART TX pad to open-drain, handle self-echo. The controller's ~740 Ω pull-up provides the highs; levels are a clean 0 ↔ 3.3 V.

## Amphenol J3 pin map (CORRECTED — connector is 180° rotated from first pass)

The original assignment was mirror-imaged; each signal moved from pin N to pin
13−N. Corrected map below.

| Pin (Odd/Even) | Amphenol | Signal |
|---|---|---|
| 1 | B1 | +5V | 2 | A1 | NC |
| 3 | B2 | BRK_SIG | 4 | A2 | NC |
| 5 | B3 | GND | 6 | A3 | GND |
| 7 | B4 | GND | 8 | A4 | BUS_DATA |
| 9 | B5 | THR_SIG | 10 | A5 | PACK_41V |
| 11 | B6 | +5V | 12 | A6 | +5V |

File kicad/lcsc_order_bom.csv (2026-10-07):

Comment | Footprint | LCSC Part Number | Quantity
100nF 0805 | C_0805 | C49678 | 35
10uF 0805 16V X5R | C_0805 | C1713 | 15
100k 0805 | C_0805 | C17407 | 30
4.7k 0805 | C_0805 | C17673 | 10
470k 0805 | C_0805 | C17709 | 5
33k 0805 | C_0805 | C17633 | 5
1k 0805 | C_0805 | C17513 | 5
1M 0805 | C_0805 | C17514 | 5
100R 0805 | C_0805 | C17408 | 5
BZT52C3V3 zener SOD-123 | D_SOD-123 | C173413 | 15
SMF3.3A TVS SOD-123 | SOD-123 | C2917875 | 5
2N7002 SOT-23 | SOT-23 | C8545 | 5
WS2812B-B/W PLCC4 | LED_5050 | C114586 | 5
HYG-8503A buzzer | BUZ-SMD | C18623826 | 5
Amphenol 98424-F52-12ALF | CONN-SMD 2mm | C239063 | 5
JST-GH SM04B-GHS-TB | JST_GH RA | C189895 | 5
LSM6DS3TR-C IMU LGA-14 | LGA-14 | C967633 | 5
OLED 2.42in SSD1309 I2C white | module | C7466001 | 5

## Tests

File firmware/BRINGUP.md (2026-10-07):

# Hardware bring-up checklist

Step-by-step validation for a freshly assembled board. Work through it **in
order** — each step de-risks the next. Keep the wheel **off the ground** (on a
stand) until the very end.

> ⚠️ This controls a vehicle. Read [`../DISCLAIMER.md`](../DISCLAIMER.md). The
> firmware defaults to throttle 0; don't defeat the interlocks during bring-up.

Most checks use the USB serial console (`idf.py -p <PORT> monitor`, prompt
`scooter>`) — see [README.md](README.md#usb-serial-console).

## 0. Board power & flash
- [ ] Inspect the board; no solder bridges, correct part orientations (U2 IMU, J3 Amphenol).
- [ ] Power the XIAO over USB-C; flash: `idf.py -p <PORT> flash monitor`.
- [ ] Boot log shows config load, bus up, `ride loop started`; LED/buzzer boot chirp.
- [ ] `status` → `link=0 locked=1` (boots locked, no controller yet). Good baseline.

## 1. Status LED & buzzer
- [ ] LED shows **purple** (locked) at boot. `set led_brightness` changes it.
- [ ] Boot chirp heard. `set buzzer_enable false` silences feedback; re-enable after.

## 2. One-wire bus (the #1 risk — open-drain single wire)
- [ ] With a scope on D6/D7: confirm the 50 Hz poll frames and that **TX idles high**
      (open-drain + controller/divider pull-up), driven low cleanly (~0.4 V).
- [ ] Connect to the motor controller (original control board **disconnected** —
      never two masters). `status` → `link=1`, and `speed`/`soc`/`current` populate.
- [ ] Confirm the software echo-filter works: no garbage frames, telemetry stable
      (cross-check values against `../pi_sniff.py` on a separate logger if unsure).

## 3. Throttle & brake inputs
- [ ] `cal start` → sweep throttle fully, squeeze brake fully → `cal apply`.
- [ ] `status`/`get` reflect sane endpoints. Throttle maps 0→255 across travel.
- [ ] `brk_active_pct` threshold feels right (brake "engages" near half travel).

## 4. Ride interlocks (wheel on a stand!)
- [ ] Stationary + throttle → **no motion** (kick-to-start). Spin the wheel by hand,
      then release-and-apply throttle → motor engages. Brake → throttle forced 0.
- [ ] Yank the bus connector mid-"ride" → **fault chirp**, throttle inhibited (`link=0`).
- [ ] Soft-start feels smooth (tune `soft_start_ms`); cap via `throttle_cap`.

## 5. IMU (LSM6DS3TR-C)
- [ ] Boot log: `LSM6DS3TR-C up` (WHO_AM_I = 0x6A at I²C 0x6A). If "not found",
      check SA0→GND, SCL/SDA, and R11/R12 pull-ups.
- [ ] **Re-check the register sequence vs the datasheet** (`imu.c`) — wake bits are
      datasheet-derived, unverified on hardware.
- [ ] Idle keep-alive: at a simulated stop, small jostles keep it from auto-locking.

## 6. OLED (SSD1309 via JST-GH)
- [ ] Connect the OLED; boot log shows `OLED up` (the I²C probe detects 0x3C).
- [ ] Display shows speed / SoC / state / current / pack V. If garbled, the SSD1309
      may need a different init than the SSD1306 driver — note and adjust.

## 7. Lights (verify against the real controller)
- [ ] Headlight comes on while moving (`headlight_mode` = auto).
- [ ] **Brake strobe is experimental**: confirm toggling the tail flag (0x08) on
      brake actually blinks the tail. If it misbehaves, `set brakelight_mode 0` (steady).

## 8. Lock / security / power
- [ ] Unlock gesture: hold brake + blip throttle 3× (stopped) → unlock chirp, `locked=0`.
- [ ] Auto-lock after `auto_lock_timeout_s` idle; motion alarm when moved while locked.
- [ ] Deep sleep: idle past `auto_sleep_timeout_s` → lights clear, current drops to µA;
      a tap (IMU) wakes it, it reboots **locked**, polling resumes.

## 9. WiFi config portal + OTA
- [ ] `wifi on` (or the brake+20 s gesture) → join `ap_ssid` @ 192.168.4.1.
- [ ] Settings save; live status updates; **OTA** a new build and confirm it reboots
      into it (the spare OTA slot).

## 10. Pack voltage
- [ ] `status` pack V matches a meter on the pack (within divider tolerance). Tune the
      divider constants in `board.h` if off.

---

When all boxes are ticked, the board is ride-ready. Change settings any time via
the console or web portal — no reflash needed.

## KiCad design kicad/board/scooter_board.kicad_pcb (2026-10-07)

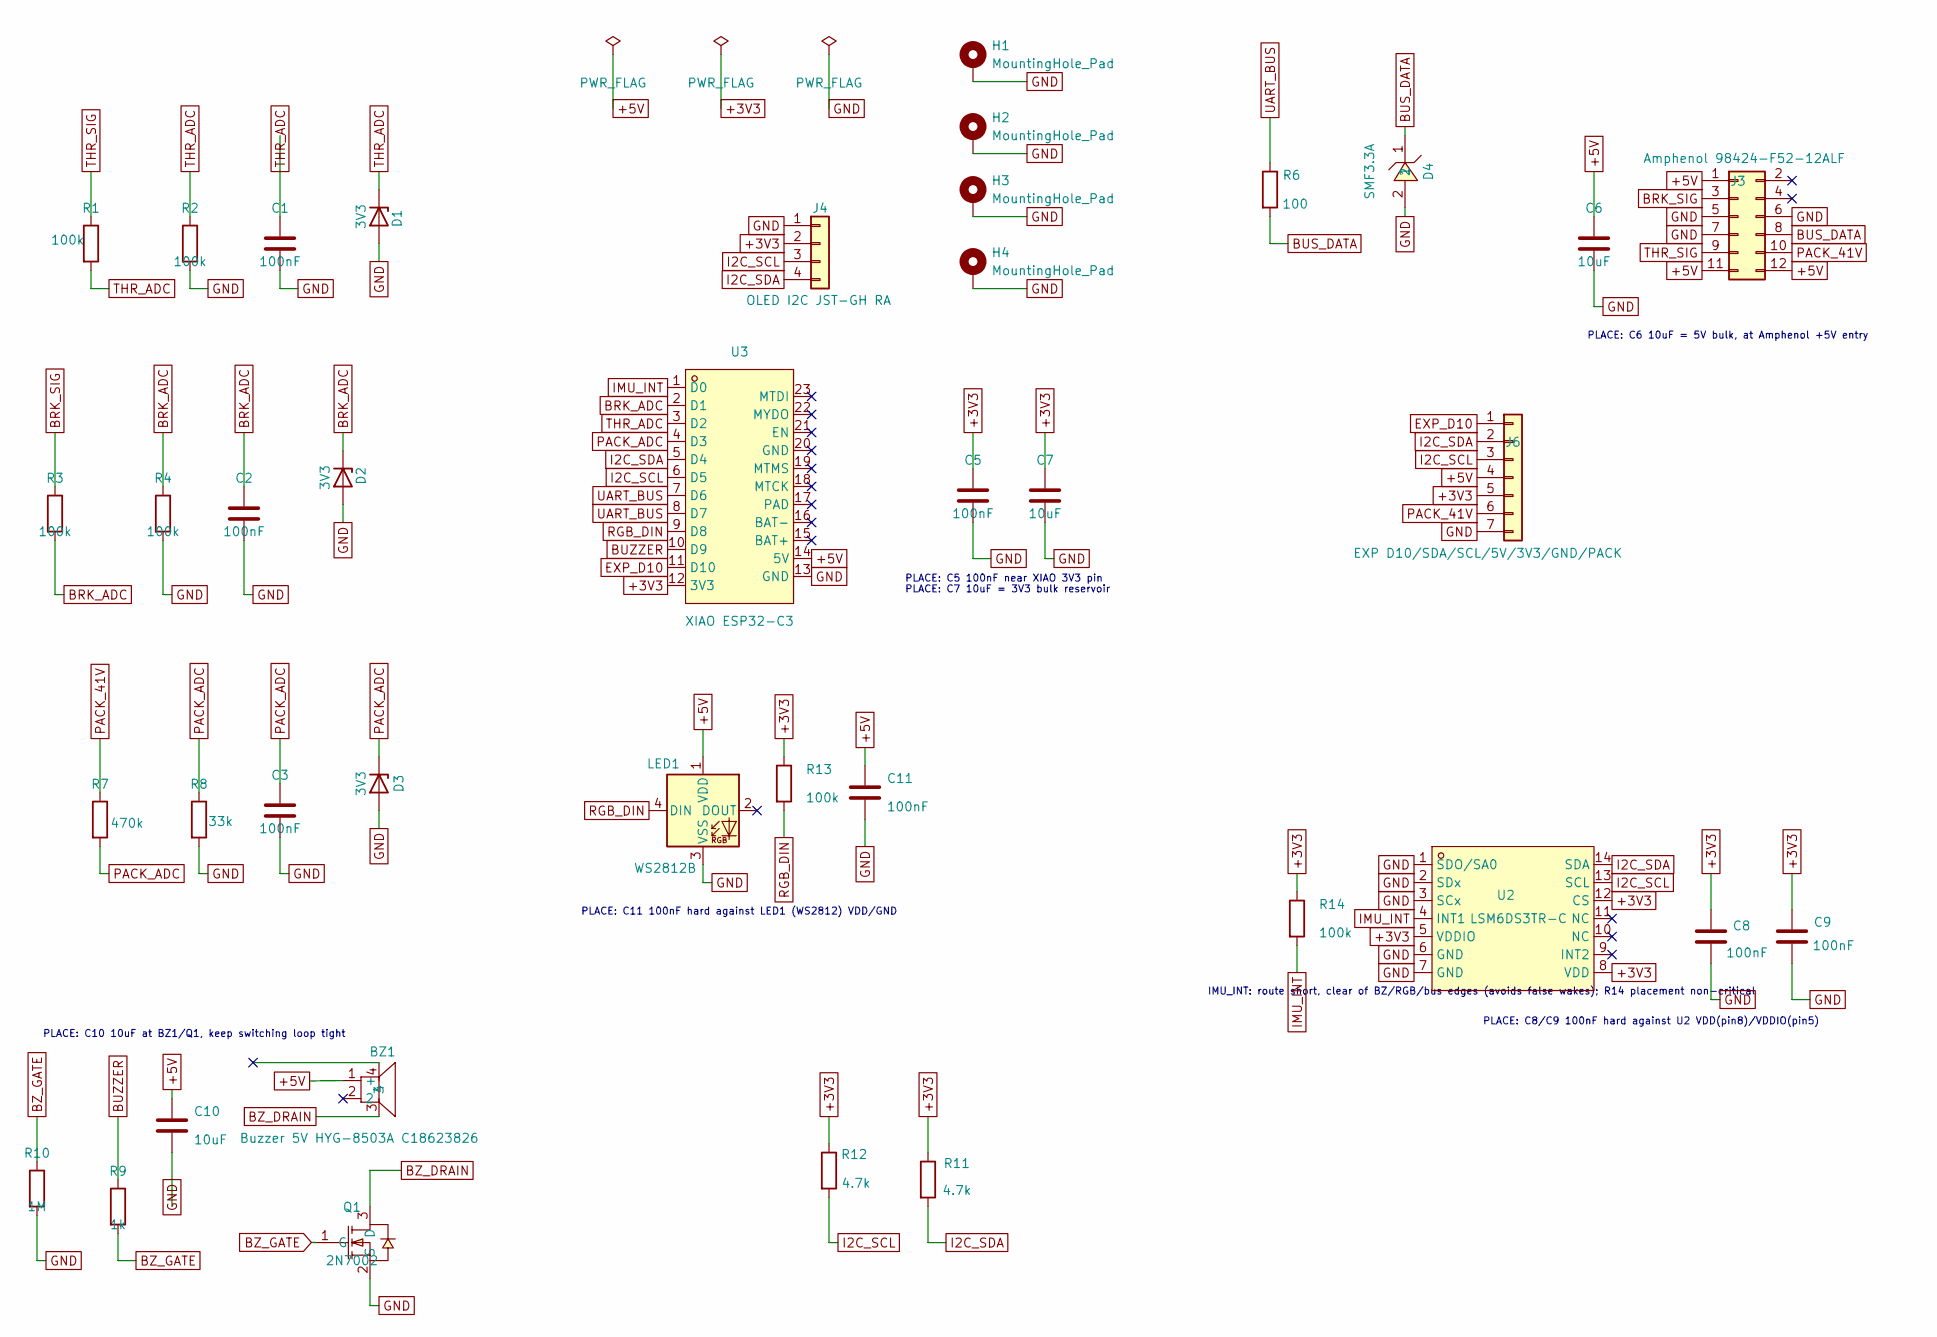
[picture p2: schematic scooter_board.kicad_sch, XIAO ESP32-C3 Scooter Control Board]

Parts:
BZ1: Buzzer 5V HYG-8503A C18623826; BUZ-SMD_4P-L8.5-W8.5-P8.50-TL-A; LCSC C18623826
C1, C2, C3, C5, C8, C9, C11: 100nF; C_0805_2012Metric; LCSC C49678
C6, C7, C10: 10uF; C_0805_2012Metric; LCSC C1713
D1, D2, D3: 3V3; D_SOD-123; LCSC C173413
D4: SMF3.3A; SOD-123_L2.8-W1.8-LS3.7-RD; LCSC C2917875
H1, H2, H3, H4: MountingHole_Pad; MountingHole_3.2mm_M3_DIN965_Pad_TopBottom
J3: Amphenol 98424-F52-12ALF; CONN-SMD_12P-P2.00-V-R2-C6-LS9.0; LCSC C239063
J4: OLED I2C JST-GH RA; JST_GH_SM04B-GHS-TB_1x04-1MP_P1.25mm_Horizontal; LCSC C189895
J6: EXP D10/SDA/SCL/5V/3V3/GND/PACK; PinHeader_1x07_P2.54mm_Vertical; LCSC C2337
LED1: WS2812B; LED_WS2812B_PLCC4_5.0x5.0mm_P3.2mm; LCSC C114586
Q1: 2N7002; SOT-23-3_L2.9-W1.3-P1.90-LS2.4-BR; LCSC C8545
R1, R2, R3, R4, R13, R14: 100k; R_0805_2012Metric; LCSC C17407
R6: 100; R_0805_2012Metric; LCSC C17408
R7: 470k; R_0805_2012Metric; LCSC C17709
R8: 33k; R_0805_2012Metric; LCSC C17633
R9: 1k; R_0805_2012Metric; LCSC C17513
R10: 1M; R_0805_2012Metric; LCSC C17514
R11, R12: 4.7k; R_0805_2012Metric; LCSC C17673
U2: LSM6DS3TR-C; LGA-14_L3.0-W2.5-P0.50-TL; LCSC C967633
U3: XIAO ESP32-C3; CONN-SMD_XIAO_ESP32C3; LCSC C19189385

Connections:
+3V3: C5.1, C7.1, C8.1, C9.1, J4.2, J6.5, R11.1, R12.1, R13.1, R14.1, U2.5 (VDDIO), U2.8 (VDD), U2.12 (CS), U3.12 (3V3)
+5V: BZ1.1 (+), C6.1, C10.1, C11.1, J3.1, J3.11, J3.12, J6.4, LED1.1 (VDD), U3.14 (5V)
BRK_ADC: C2.1, D2.1 (K), R3.2, R4.1, U3.2 (D1)
BRK_SIG: J3.3, R3.1
BUS_DATA: D4.1, J3.8, R6.2
BUZZER: R9.1, U3.10 (D9)
BZ_DRAIN: BZ1.3, Q1.3 (D)
BZ_GATE: Q1.1 (G), R9.2, R10.1
EXP_D10: J6.1, U3.11 (D10)
GND: C1.2, C2.2, C3.2, C5.2, C6.2, C7.2, C8.2, C9.2, C10.2, C11.2, D1.2 (A), D2.2 (A), D3.2 (A), D4.2, H1.1 (1_1), H2.1 (1_1), H3.1 (1_1), H4.1 (1_1), J3.5, J3.6, J3.7, J4.1, J4.MP, J6.7, LED1.3 (VSS), Q1.2 (S), R2.2, R4.2, R8.2, R10.2, U2.1 (SDO/SA0), U2.2 (SDx), U2.3 (SCx), U2.6 (GND), U2.7 (GND), U3.13 (GND)
I2C_SCL: J4.3, J6.3, R12.2, U2.13 (SCL), U3.6 (D5)
I2C_SDA: J4.4, J6.2, R11.2, U2.14 (SDA), U3.5 (D4)
IMU_INT: R14.2, U2.4 (INT1), U3.1 (D0)
PACK_41V: J3.10, J6.6, R7.1
PACK_ADC: C3.1, D3.1 (K), R7.2, R8.1, U3.4 (D3)
RGB_DIN: LED1.4 (DIN), R13.2, U3.9 (D8)
THR_ADC: C1.1, D1.1 (K), R1.2, R2.1, U3.3 (D2)
THR_SIG: J3.9, R1.1
UART_BUS: R6.1, U3.7 (D6), U3.8 (D7)

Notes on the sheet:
PLACE: C10 10uF at BZ1/Q1, keep switching loop tight
PLACE: C7 10uF = 3V3 bulk reservoir
PLACE: C8/C9 100nF hard against U2 VDD(pin8)/VDDIO(pin5)
PLACE: C5 100nF near XIAO 3V3 pin
PLACE: C6 10uF = 5V bulk, at Amphenol +5V entry
PLACE: C11 100nF hard against LED1 (WS2812) VDD/GND
IMU_INT: route short, clear of BZ/RGB/bus edges (avoids false wakes); R14 placement non-critical

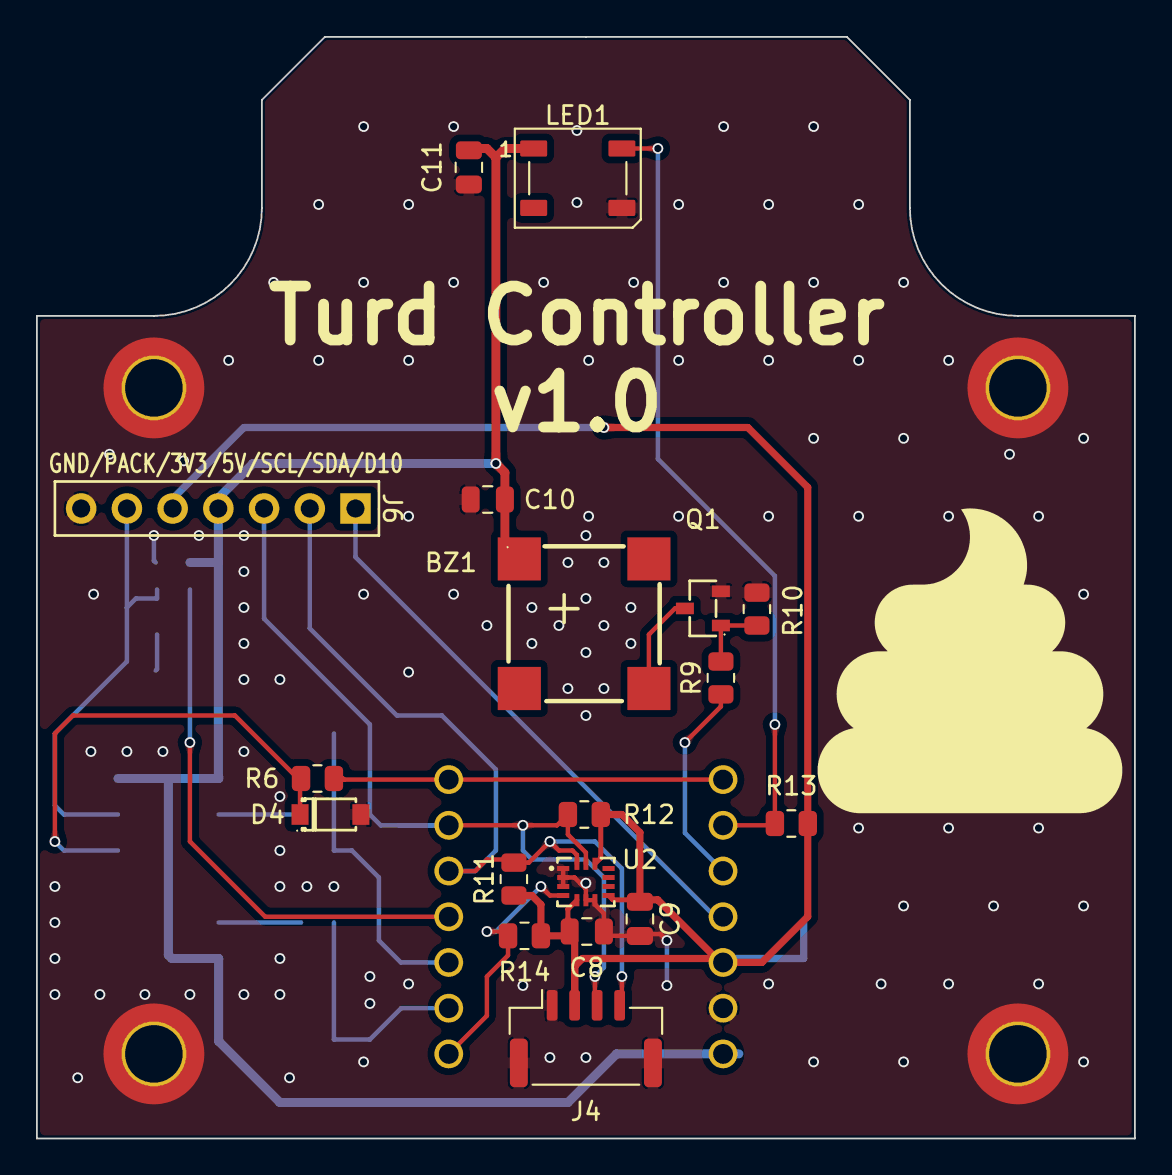
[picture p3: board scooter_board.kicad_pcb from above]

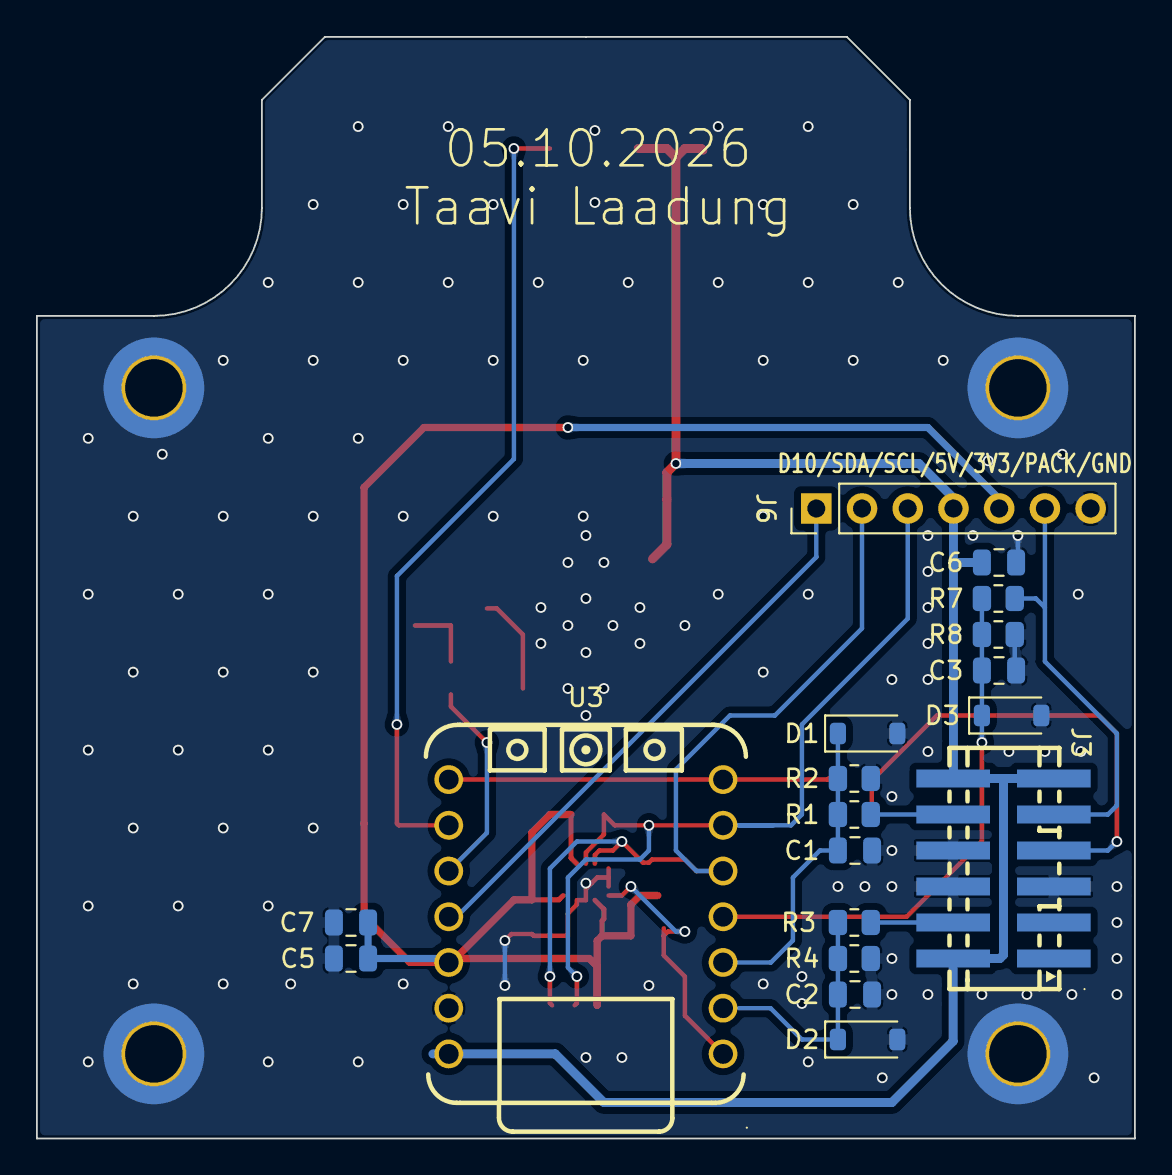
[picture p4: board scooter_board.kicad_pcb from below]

Board: 2 copper layers, 61.0 x 61.2 mm, 39 parts (18 on the bottom side), 19 nets.

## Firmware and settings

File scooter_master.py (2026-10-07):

#!/usr/bin/env python3
# SPDX-License-Identifier: GPL-3.0-or-later
# Copyright 2026 Taavi Laadung
"""
scooter_master.py - act as the scooter's control board on the one-wire bus.

Talks to the motor controller with the colon protocol reverse-engineered on
2026-09-11:

    ':' TYPE LEN DATA[LEN] CHK CR LF        CHK = XOR of ':' TYPE LEN DATA

    0x1A poll, 50 Hz, DATA = [throttle 0..255, flags]
         flags: 0x08 always set (tail light), 0x10 = request status
                (every 5th poll), 0x40 = headlight
    0x10 status reply, 21 bytes, big-endian 16-bit fields
    0x1B "SN" -> 0x11 serial numbers      0x1D "FW" -> 0x13 firmware string
    0x1E [20 10] -> 0x14 echo, 0x1F [02 F4], 0x20 [00 87]: one-shot boot frames

Wiring (control board DISCONNECTED from the data line), verified 2026-09-11:
    adapter GND -> scooter GND
    adapter RX  -> data line (direct)
    adapter TX  -> 100 ohm resistor -> data line
    The controller holds the line high through about 740 ohm, so a diode-OR
    from TX (tried 1N4007) only reaches ~1.3 V low and the controller ignores
    us; 1 kohm in series gives 1.9 V, also ignored; 100 ohm gives a valid low
    and works. The resistor limits contention current (~30 mA for ~2 ms)
    while the controller replies against our idle-high TX. For a permanent
    install use an open-drain buffer (74HC07 / 74LVC07) instead.

Because RX sees our own transmissions, every frame we send comes back as an
echo. The script verifies each echo; a mismatch means a bus collision.

Keys (hold-to-run by default, throttle drops to 0 within ~250 ms of release):
    w          hold to apply throttle at the current level
    1..9, 0    set level 10%..90%, 100%        + / -   level +-5
    space, b   throttle 0 now, latch off
    l          toggle latch (throttle stays applied WITHOUT holding w)
    h          headlight: auto (on when moving) -> on -> off
    n / v      send SN / FW query
    e / f / g  send boot one-shots 0x1E, 0x1F, 0x20
    x          raw frame: then type  TYPE HEXDATA  and Enter, e.g.  1e 2010

    Experiments (see EXPERIMENTS below):
    F          flag scan: sweep candidate poll flag bits (0,2,5,7). Run at FULL
               throttle + spinning. (Bit 1 / 0x02 is excluded: it CUTS drive.)
    z          hold one flag byte until cleared: type a hex byte, e.g.
               0c (bit2), 28 (bit5), 88 (bit7). Empty input or k clears it.
    c          config fuzz: type  TYPE p1 p2 ...  e.g.  1f 02f4 0300 04b0 05dc
               (sends each payload, then restores the factory value)
    B          boot inject: type overrides e.g.  1f=07d0 20=00ff  then
               power-cycle the controller. Polling keeps running (tail light
               stays on); when the READY banner arrives the script injects the
               boot handshake (SN, FW, 1E, 1F, 20) with your values. Use this to
               test config that the controller only reads at startup.
    k          cancel the running sequence / clear a held flag byte

    p          pause/resume polling (see how the controller reacts to silence)
    q          quit (sends zero-throttle polls first)

EXPERIMENTS (looking for the speed limiter and kick-start settings)

  The controller is a Nanjing Lishui LSW6G-RF-FOC with Bird's own firmware.
  The limiter (~25 km/h, speed reading caps at 156) and kick-to-start are
  controller config, not per-frame commands. The original board only ever
  wrote three config-looking frames at boot: 0x1E=2010, 0x1F=02F4, 0x20=0087.
  We previously re-sent those SAME values, so nothing changed. The untried
  experiment is to send DIFFERENT values, and to try the poll flag bits the
  board never set.

  SAFETY: config writes may persist and may make the controller behave
  unexpectedly (sudden power, changed limits). Always: wheel OFF the ground,
  current-limited bench supply if possible, and note that 'c' auto-restores
  the factory value after each sweep. Factory values are logged at startup
  (grep FACTORY in the raw log) so you can always write them back by hand.

  Flag scan (F): spin the wheel and keep it spinning through the whole scan.
  Watch the speed reading. If it climbs past ~156 with a bit set, that bit
  lifts the limiter. If the motor engages while the wheel is NOT spinning with
  a bit set, that bit disables kick-start.

  Config fuzz (c): step a config register. Examples to try, one line at a time:
     1f 02f4 0384 03e8 044c 04b0 0514      (0x1F around 756: 900,1000,...,1300)
     20 0087 0064 00a0 00c8 00ff           (0x20 around 135)
     1e 2010 2020 2040 2080 20ff           (0x1E high nibble / low byte)
  After each line, watch whether the limiter or kick-start behavior changed on
  a spin+throttle test, then move to the next.

Logs go to ./logs/<timestamp>_raw.txt (every frame, both directions) and
./logs/<timestamp>_status.csv (decoded status frames).
"""
import argparse
import collections
import csv
import os
import sys
import time

import serial

try:
    import msvcrt
except ImportError:  # not Windows
    msvcrt = None

POLL_PERIOD = 0.020
STATUS_EVERY = 5
HOLD_TIMEOUT = 0.4
BOOT_INJECT_DELAY = 1.0       # seconds after the READY banner before injecting
WHEEL_CIRC_M = 0.70          # 222 mm wheel; odometer = 1 count per revolution
SPEED_KMH_PER_UNIT = 0.1609  # hypothesis: speed byte is in 0.1 mph

OUR_TYPES = {0x1A, 0x1B, 0x1D, 0x1E, 0x1F, 0x20}


def build(ftype, data):
    body = bytes([0x3A, ftype, len(data)]) + bytes(data)
    x = 0
    for b in body:
        x ^= b
    return body + bytes([x, 0x0D, 0x0A])


class Parser:
    """Feeds bytes, yields ("frame", type, data) or ("junk", byte, None)."""

    def __init__(self):
        self.buf = bytearray()

    def feed(self, chunk):
        self.buf += chunk
        out = []
        while self.buf:
            if self.buf[0] != 0x3A:
                out.append(("junk", self.buf[0], None))
                del self.buf[0]
                continue
            if len(self.buf) < 3:
                break
            length = self.buf[2]
            if length > 64:
                out.append(("junk", self.buf[0], None))
                del self.buf[0]
                continue
            end = 3 + length + 3
            if len(self.buf) < end:
                break
            body = self.buf[:end]
            x = 0
            for b in body[: 3 + length]:
                x ^= b
            if body[3 + length] == x and body[end - 2] == 0x0D and body[end - 1] == 0x0A:
                out.append(("frame", body[1], bytes(body[3 : 3 + length])))
                del self.buf[:end]
            else:
                out.append(("junk", self.buf[0], None))
                del self.buf[0]
        return out


def be16(d, i):
    return (d[i] << 8) | d[i + 1]


def decode_status(d):
    if len(d) < 21:
        return None
    odo = (d[15] << 16) | (d[16] << 8) | d[17]
    return {
        "v1_raw": be16(d, 0),          # 2970..3000, rises under load; not simply pack V
        "v2_raw": be16(d, 2),
        "current_A": be16(d, 4) / 100.0,  # 0.01 A (10 mA) units
        "b6": d[6],
        "charge_A": d[7] / 100.0,      # 0.01 A units; 0 with charger unplugged
        "soc_pct": be16(d, 8),
        "b10": d[10],
        "b11": d[11],
        "speed_raw": d[12],
        "speed_kmh_est": round(d[12] * SPEED_KMH_PER_UNIT, 1),
        "b13": d[13],
        "b14": d[14],
        "odo_rev": odo,
        "odo_km_est": round(odo * WHEEL_CIRC_M / 1000.0, 2),
        "b18": d[18],
        "b19": d[19],
        "b20": d[20],
    }


class Master:
    def __init__(self, port, baud, boot):
        self.ser = serial.Serial(port, baud, timeout=0)
        self.parser = Parser()
        self.level = 0
        self.hold_until = 0.0
        self.latch = False
        self.headlight_mode = "auto"
        self.paused = False
        self.extra = collections.deque()
        self.expect_echo = collections.deque()
        self.echo_ok = 0
        self.echo_bad = 0
        self.junk = 0
        self.status = None
        self.status_count = 0
        self.last_status_t = 0.0
        self.messages = collections.deque(maxlen=6)
        self.raw_mode = False
        self.raw_buf = ""
        self.raw_kind = None        # what the current raw-input line is for
        self.flag_override = None    # forces the poll flag byte during a scan
        self.boot_inject = None      # dict {type:data} to send after next READY
        self.boot_fire_at = None     # perf_counter time to fire the injection
        self._readytail = b""        # rolling tail for raw READY-banner detection
        self.seq = None              # active experiment sequence (deque of steps)
        self.seq_next = 0.0          # perf_counter time to advance to next step
        self.seq_label = ""
        self.t0 = time.perf_counter()
        os.makedirs("logs", exist_ok=True)
        stamp = time.strftime("%Y%m%d_%H%M%S")
        self.rawlog = open(f"logs/{stamp}_raw.txt", "w", buffering=1)
        self.csvf = open(f"logs/{stamp}_status.csv", "w", newline="")
        self.csv = None
        # Factory boot-frame values, as the original Bird board sent them.
        # Kept so a config fuzz can always be restored to stock.
        self.factory = {0x1E: b"\x20\x10", 0x1F: b"\x02\xF4", 0x20: b"\x00\x87"}
        self.rawlog.write("FACTORY boot frames (restore targets): "
                          + " ".join(f"{t:02x}={d.hex()}" for t, d in self.factory.items())
                          + "\n")
        if boot:
            for t, d in ((0x1B, b"SN"), (0x1D, b"FW"), (0x1E, b"\x20\x10"),
                         (0x1F, b"\x02\xF4"), (0x20, b"\x00\x87")):
                self.extra.append((t, d))

    # ---------- helpers ----------
    def now(self):
        return time.perf_counter() - self.t0

    def log(self, direction, ftype, data):
        self.rawlog.write(f"{self.now():10.4f} {direction} {ftype:02x} {data.hex()}\n")

    def send(self, ftype, data):
        f = build(ftype, data)
        self.ser.write(f)
        self.expect_echo.append((ftype, bytes(data)))
        self.log("TX", ftype, bytes(data))

    def throttle_now(self):
        if self.latch:
            return self.level
        return self.level if time.perf_counter() < self.hold_until else 0

    def headlight_on(self):
        if self.headlight_mode == "on":
            return True
        if self.headlight_mode == "off":
            return False
        return bool(self.status and self.status["speed_raw"] > 0)

    # ---------- receive ----------
    def pump(self):
        chunk = self.ser.read(4096)
        if not chunk:
            return
        # The controller's power-up banner (":\x1dREADY\r\n") is raw text, not a
        # checksummed frame, so the frame parser discards it. Detect it here on
        # the raw byte stream instead.
        combined = self._readytail + chunk
        if b"READY" in combined:
            self._readytail = b""
            self.on_ready()
        else:
            self._readytail = combined[-8:]
        for kind, a, b in self.parser.feed(chunk):
            if kind == "junk":
                self.junk += 1
                self.rawlog.write(f"{self.now():10.4f} JUNK {a:02x}\n")
                continue
            ftype, data = a, b
            if ftype in OUR_TYPES:
                exp = self.expect_echo.popleft() if self.expect_echo else None
                if exp == (ftype, data):
                    self.echo_ok += 1
                else:
                    self.echo_bad += 1
                    self.log("ECHO?", ftype, data)
                continue
            self.log("RX", ftype, data)
            if ftype == 0x10:
                st = decode_status(data)
                if st:
                    self.status = st
                    self.status_count += 1
                    self.last_status_t = time.perf_counter()
                    row = {"t": round(self.now(), 3), "throttle": self.throttle_now(), **st, "raw": data.hex()}
                    if self.csv is None:
                        self.csv = csv.DictWriter(self.csvf, fieldnames=list(row))
                        self.csv.writeheader()
                    self.csv.writerow(row)
            else:
                printable = all(32 <= c < 127 for c in data)
                text = data.decode("ascii", "replace") if printable else ""
                self.messages.append(f"{self.now():8.2f} RX {ftype:02x} {data.hex()} {text}")

    # ---------- keyboard ----------
    def keys(self):
        if not msvcrt:
            return
        while msvcrt.kbhit():
            ch = msvcrt.getwch()
            if self.raw_mode:
                if ch in "\r\n":
                    self.raw_mode = False
                    try:
                        parts = self.raw_buf.split()
                        if self.raw_kind == "fuzz":
                            # "TYPE p1 p2 p3 ..." each p is a hex payload
                            ftype = int(parts[0], 16)
                            payloads = [bytes.fromhex(p) for p in parts[1:]]
                            if not payloads:
                                raise ValueError("need at least one payload")
                            self.start_seq(self.build_config_fuzz(ftype, payloads),
                                           f"fuzz {ftype:02x} x{len(payloads)}")
                        elif self.raw_kind == "boot":
                            # "1f=07d0 20=00ff" -> arm boot injection with overrides
                            ov = {}
                            for tok in parts:
                                k, v = tok.split("=")
                                ov[int(k, 16)] = bytes.fromhex(v)
                            self.arm_boot_inject(ov)
                        elif self.raw_kind == "flags":
                            # hold a flag byte until cleared (k). "" clears.
                            if not parts:
                                self.flag_override = None
                                self.messages.append("flag hold cleared")
                            else:
                                self.flag_override = int(parts[0], 16)
                                self.messages.append(f"holding flags 0x{self.flag_override:02x} (k to clear)")
                        else:
                            t, h = parts
                            self.extra.append((int(t, 16), bytes.fromhex(h)))
                            self.messages.append(f"queued raw {t} {h}")
                    except Exception as e:  # noqa: BLE001
                        self.messages.append(f"bad input: {e}")
                    self.raw_buf = ""
                    self.raw_kind = None
                elif ch == "\x1b":
                    self.raw_mode = False
                    self.raw_buf = ""
                    self.raw_kind = None
                else:
                    self.raw_buf += ch
                continue
            if ch == "w":
                self.hold_until = time.perf_counter() + HOLD_TIMEOUT
            elif ch in "1234567890":
                self.level = 255 if ch == "0" else int(ch) * 255 // 10
            elif ch == "+":
                self.level = min(255, self.level + 5)
            elif ch == "-":
                self.level = max(0, self.level - 5)
            elif ch in (" ", "b"):
                self.level = 0
                self.latch = False
                self.hold_until = 0
            elif ch == "l":
                self.latch = not self.latch
            elif ch == "h":
                self.headlight_mode = {"auto": "on", "on": "off", "off": "auto"}[self.headlight_mode]
            elif ch == "n":
                self.extra.append((0x1B, b"SN"))
            elif ch == "v":
                self.extra.append((0x1D, b"FW"))
            elif ch == "e":
                self.extra.append((0x1E, b"\x20\x10"))
            elif ch == "f":
                self.extra.append((0x1F, b"\x02\xF4"))
            elif ch == "g":
                self.extra.append((0x20, b"\x00\x87"))
            elif ch == "x":
                self.raw_mode = True
                self.raw_kind = "frame"
                self.raw_buf = ""
            elif ch == "F":
                self.start_seq(self.build_flag_scan(), "flag scan")
            elif ch == "z":
                self.raw_mode = True
                self.raw_kind = "flags"
                self.raw_buf = ""
                self.messages.append("hold flags: type a hex byte e.g. 0c (bit2), 28 (bit5), 88 (bit7); empty=clear")
            elif ch == "B":
                self.raw_mode = True
                self.raw_kind = "boot"
                self.raw_buf = ""
                self.messages.append("boot-inject: type overrides e.g.  1f=07d0 20=00ff  (then power-cycle controller)")
            elif ch == "c":
                self.raw_mode = True
                self.raw_kind = "fuzz"
                self.raw_buf = ""
                self.messages.append("fuzz: type  TYPE p1 p2 ...  e.g.  1f 02f4 0300 04b0 05dc")
            elif ch == "k":
                self.cancel_seq()
            elif ch == "p":
                self.paused = not self.paused
            elif ch == "q":
                raise KeyboardInterrupt

    # ---------- experiment sequences ----------
    # A sequence is a deque of steps. Each step:
    #   {"dur": seconds, "flags": int|None, "send": [(type,data),...], "note": str}
    # While a sequence runs, polling continues; the flag byte is overridden when
    # "flags" is set, and any "send" frames are queued once at step start.
    def start_seq(self, steps, label):
        if self.seq:
            self.messages.append("a sequence is already running; press k to cancel")
            return
        self.seq = collections.deque(steps)
        self.seq_label = label
        self.seq_next = time.perf_counter()   # advance immediately to first step
        self.rawlog.write(f"{self.now():10.4f} SEQ-START {label}\n")
        self.messages.append(f"sequence started: {label}")

    def cancel_seq(self):
        if self.seq is not None:
            self.rawlog.write(f"{self.now():10.4f} SEQ-CANCEL {self.seq_label}\n")
            self.messages.append(f"sequence cancelled: {self.seq_label}")
        self.seq = None
        self.flag_override = None

    def seq_tick(self, now):
        if self.seq is None or now < self.seq_next:
            return
        # log the status snapshot captured at the END of the step just finished
        if self.status:
            s = self.status
            self.rawlog.write(f"{self.now():10.4f} SEQ-SNAP spd={s['speed_raw']} "
                              f"I={s['current_A']:.2f} v1={s['v1_raw']} v2={s['v2_raw']} "
                              f"b13={s['b13']:02x} b19={s['b19']:02x} b20={s['b20']} "
                              f"soc={s['soc_pct']}\n")
        if not self.seq:
            self.messages.append(f"sequence done: {self.seq_label}")
            self.rawlog.write(f"{self.now():10.4f} SEQ-END {self.seq_label}\n")
            self.seq = None
            self.flag_override = None
            return
        step = self.seq.popleft()
        self.seq_next = now + step.get("dur", 1.0)
        self.flag_override = step.get("flags")
        for t, d in step.get("send", []):
            self.extra.append((t, d))
        note = step.get("note", "")
        self.rawlog.write(f"{self.now():10.4f} SEQ-STEP {note} flags={self.flag_override} "
                          f"send={[f'{t:02x}:{d.hex()}' for t,d in step.get('send',[])]}\n")
        if note:
            self.messages.append(f"[{self.seq_label}] {note}")

    def build_flag_scan(self, dwell=3.0, bits=(0, 2, 5, 7)):
        """Sweep candidate poll flag bits. For each: dwell with it clear, then
        dwell with it set. Bit 1 (0x02) is excluded by default because it was
        found to CUT motor drive (coast), which would stop the wheel and spoil
        the rest of the sweep. Run at FULL throttle (press 0, l) and keep the
        wheel spinning so speed sits at 156 -- then a lifted limiter shows as
        speed climbing past 156 during a 'bit ON' phase."""
        base = 0x08
        steps = [{"dur": dwell, "flags": base,
                  "note": "baseline. Full throttle + spin; speed should sit ~156."}]
        for bit in bits:
            steps.append({"dur": dwell, "flags": base,
                          "note": f"bit {bit} (0x{1 << bit:02x}) OFF"})
            steps.append({"dur": dwell, "flags": base | (1 << bit),
                          "note": f"bit {bit} (0x{1 << bit:02x}) ON  <- watch speed cap / engagement"})
        steps.append({"dur": 1.0, "flags": base, "note": "flag scan complete"})
        return steps

    def on_ready(self):
        """Called when the controller's READY banner is seen on the raw stream."""
        self.log("RX", 0x1D, b"READY")
        self.messages.append(f"{self.now():8.2f} controller READY banner")
        if self.boot_inject is not None and self.boot_fire_at is None:
            self.boot_fire_at = time.perf_counter() + BOOT_INJECT_DELAY
            self.messages.append(f"READY seen -> injecting config in {BOOT_INJECT_DELAY:.1f}s")

    def arm_boot_inject(self, overrides):
        """Arm injection of the boot config frames after the next READY banner.
        `overrides` is {type:data}; types not given use the factory value.
        Polling keeps running so the tail light stays on and the controller
        sees normal bus activity while it boots."""
        self.boot_inject = overrides
        self.boot_fire_at = None
        show = " ".join(f"{t:02x}={d.hex()}" for t, d in overrides.items()) or "(factory)"
        self.rawlog.write(f"{self.now():10.4f} BOOT-ARM {show}\n")
        self.messages.append(f"boot-inject ARMED ({show}). Power-cycle the controller now; waiting for READY.")
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

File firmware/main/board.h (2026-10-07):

// SPDX-License-Identifier: GPL-3.0-or-later
// Copyright 2026 Taavi Laadung
//
// board.h - one place for the XIAO ESP32-C3 pin map and firmware tunables.
// Silk labels (D0..D10) are the XIAO's; GPIOs are the ESP32-C3's.

#pragma once

#include "driver/gpio.h"
#include "hal/adc_types.h"
#include "driver/uart.h"

// ---- Pin map (XIAO silk -> GPIO) --------------------------------------------
#define PIN_IMU_INT       GPIO_NUM_2    // D0  IMU INT1 / deep-sleep wake (later)
#define PIN_BRAKE_ADC     GPIO_NUM_3    // D1  brake input     (ADC1_CH3)
#define PIN_THROTTLE_ADC  GPIO_NUM_4    // D2  throttle input  (ADC1_CH4)
#define PIN_PACK_ADC      GPIO_NUM_5    // D3  pack sense      (ADC2_CH0, later)
#define PIN_I2C_SDA       GPIO_NUM_6    // D4  OLED + IMU       (later)
#define PIN_I2C_SCL       GPIO_NUM_7    // D5  OLED + IMU       (later)
#define PIN_BUS_TX        GPIO_NUM_21   // D6  one-wire bus TX (open-drain)
#define PIN_BUS_RX        GPIO_NUM_20   // D7  one-wire bus RX (tied to D6)
#define PIN_WS2812        GPIO_NUM_8    // D8  status LED data
#define PIN_BUZZER        GPIO_NUM_9    // D9  buzzer (low-side MOSFET gate)
#define PIN_EXPANSION     GPIO_NUM_10   // D10 expansion header (unused in fw)

// ---- ADC channels (ESP32-C3) ------------------------------------------------
#define ADC_BRAKE_CHANNEL     ADC_CHANNEL_3   // GPIO3  (ADC1)
#define ADC_THROTTLE_CHANNEL  ADC_CHANNEL_4   // GPIO4  (ADC1)
#define ADC_PACK_CHANNEL      ADC_CHANNEL_0   // GPIO5  (ADC2 - blocked while WiFi runs)

// Pack voltage divider: R7 (top) / R8 (bottom). Vpack = Vnode * (top+bot)/bot.
#define PACK_DIV_R_TOP        470000          // R7
#define PACK_DIV_R_BOT        33000           // R8

// ---- One-wire bus -----------------------------------------------------------
#define BUS_UART_NUM      UART_NUM_1
#define BUS_BAUD          115200
#define POLL_PERIOD_MS    20             // 50 Hz heartbeat (PROTOCOL.md 3.1/5.2)
#define STATUS_EVERY_N    5              // request status on every 5th poll
#define BUS_LINK_TIMEOUT_US  300000      // no status for 300 ms => link lost

// ---- Buzzer -----------------------------------------------------------------
#define BUZZER_TONE_HZ    2700           // HYG-8503A is loudest near 2.7 kHz

// ---- Throttle / brake input (RAW 12-bit ADC endpoints) ----------------------
// Placeholder calibration until the real harness is on the bench. The dividers
// (R1-R4, 100k) halve the hall signal; these get replaced by a runtime
// calibration (serial-triggered) and NVS storage in a later phase.
#define THROTTLE_RAW_MIN  600            // released
#define THROTTLE_RAW_MAX  2600           // full
#define BRAKE_RAW_MIN     600            // released
#define BRAKE_RAW_MAX     2600           // full
#define THROTTLE_DEADZONE_PCT  5         // ignore the bottom 5 % of travel
#define BRAKE_ACTIVE_PCT       40        // brake "on" past ~40 % travel (PROTOCOL.md 6.3)

// ---- Control ----------------------------------------------------------------
#define THROTTLE_CMD_MAX  255            // cap sent to controller (0..255)

// ---- Gestures (percent of throttle travel; evaluated only while stationary) --
// Unlock/lock toggle: hold brake + blip the throttle GEST_TRIPLE_COUNT times.
#define GEST_BLIP_HIGH_PCT     60        // throttle must exceed this to start a blip
#define GEST_BLIP_LOW_PCT      10        // ...then drop below this to complete it
#define GEST_TRIPLE_COUNT       3
#define GEST_TRIPLE_WINDOW_MS  3000      // all blips must land within this window
// Config/OTA mode: hold brake + full throttle continuously for this long.
#define GEST_CONFIG_HIGH_PCT   90
#define GEST_CONFIG_HOLD_MS   20000      // 20 s (deliberately awkward)

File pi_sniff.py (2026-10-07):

#!/usr/bin/env python3
# SPDX-License-Identifier: GPL-3.0-or-later
# Copyright 2026 Taavi Laadung
"""
pi_sniff.py - passive one-wire bus logger for a Raspberry Pi ride recorder.

RECEIVE-ONLY. The original control board stays connected and acts as master;
this just listens on the data line and logs every status frame, so we capture
telemetry under real riding load (throttle, speed, current, and hopefully the
still-unknown pack-voltage and temperature fields).

Wiring (Pi):
    scooter GND -> Pi GND (pin 6)
    data line   -> [1k] -> Pi GPIO15 / RXD (pin 10)      (RX only, no TX)
    Power the Pi from its own battery/power bank. Never connect the pack (~41V)
    or a 5V rail to a GPIO.

The Pi UART must be free: enable_uart=1, dtoverlay=disable-bt in config.txt, no
serial console in cmdline.txt, and serial-getty disabled (the installer does the
last one).

Standard library only - no pyserial, so nothing to install on the Pi.
Linux-only (uses termios).

Usage:  pi_sniff.py [--port /dev/serial0] [--out DIR] [--quiet]
Writes  <out>/ride_YYYYmmdd_HHMMSS.csv  (full 21-byte frame + decoded fields)
and appends drift notes to <out>/ride_notes.txt.
"""
import argparse
import csv
import os
import sys
import time

NBYTES = 21


def open_serial(port, baud=115200):
    """Open a tty at 8N1 raw using only the standard library (termios)."""
    import termios  # lazy: Linux-only, keeps this file importable on Windows
    speed = getattr(termios, f"B{baud}")
    fd = os.open(port, os.O_RDWR | os.O_NOCTTY | os.O_NONBLOCK)
    iflag, oflag, cflag, lflag, ispeed, ospeed, cc = termios.tcgetattr(fd)
    iflag = 0
    oflag = 0
    lflag = 0
    cflag = termios.CS8 | termios.CREAD | termios.CLOCAL
    ispeed = ospeed = speed
    cc = list(cc)
    cc[termios.VMIN] = 0
    cc[termios.VTIME] = 0
    termios.tcsetattr(fd, termios.TCSANOW, [iflag, oflag, cflag, lflag, ispeed, ospeed, cc])
    termios.tcflush(fd, termios.TCIFLUSH)
    return fd


def read_serial(fd, n=512, timeout=0.2):
    import select
    r, _, _ = select.select([fd], [], [], timeout)
    if not r:
        return b""
    try:
        return os.read(fd, n)
    except BlockingIOError:
        return b""


def be16(d, i):
    return (d[i] << 8) | d[i + 1]


def decode(d):
    odo = (d[15] << 16) | (d[16] << 8) | d[17]
    return {
        "v1": be16(d, 0),
        "v2": be16(d, 2),
        "current_A": be16(d, 4) / 100.0,
        "charge_A": d[7] / 100.0,
        "soc": be16(d, 8),
        "b10": d[10],
        "speed": d[12],
        "b13": d[13],
        "odo": odo,
        "b18": d[18],
        "b19": d[19],
        "b20": d[20],
    }


class Parser:
    """Extract colon frames; also flags the raw READY banner."""

    def __init__(self):
        self.buf = bytearray()

    def feed(self, chunk):
        out = []
        self.buf += chunk
        if b"READY" in self.buf:
            out.append(("ready", None))
        while self.buf:
            if self.buf[0] != 0x3A:
                del self.buf[0]
                continue
            if len(self.buf) < 3:
                break
            length = self.buf[2]
            if length > 64:
                del self.buf[0]
                continue
            end = 3 + length + 3
            if len(self.buf) < end:
                break
            body = self.buf[:end]
            x = 0
            for b in body[: 3 + length]:
                x ^= b
            if body[3 + length] == x and body[end - 2] == 0x0D and body[end - 1] == 0x0A:
                out.append(("frame", (body[1], bytes(body[3 : 3 + length]))))
                del self.buf[:end]
            else:
                del self.buf[0]
        if len(self.buf) > 512:      # never grow without bound on a noisy line
            del self.buf[:-64]
        return out


def main():
    ap = argparse.ArgumentParser()
    ap.add_argument("--port", default="/dev/serial0")
    ap.add_argument("--out", default=os.path.dirname(os.path.abspath(__file__)))
    ap.add_argument("--quiet", action="store_true")
    args = ap.parse_args()

    os.makedirs(args.out, exist_ok=True)
    stamp = time.strftime("%Y%m%d_%H%M%S")
    csv_path = os.path.join(args.out, f"ride_{stamp}.csv")
    seq = 1
    while os.path.exists(csv_path):   # clock may repeat on a headless Pi; never overwrite
        seq += 1
        csv_path = os.path.join(args.out, f"ride_{stamp}_{seq}.csv")
    note_path = os.path.join(args.out, "ride_notes.txt")

    fd = None
    while fd is None:                # device may not be ready right at boot
        try:
            fd = open_serial(args.port)
        except Exception as e:  # noqa: BLE001
            print(f"waiting for {args.port}: {e}", flush=True)
            time.sleep(2)

    cf = open(csv_path, "w", newline="")
    w = csv.writer(cf)
    w.writerow(["t"] + [f"b{i}" for i in range(NBYTES)]
               + ["v1", "v2", "current_A", "charge_A", "soc", "speed", "odo", "b20"])
    note = open(note_path, "a", buffering=1)

    def log(msg):
        line = f"{stamp} {time.time()-t0:8.1f}  {msg}"
        note.write(line + "\n")
        note.flush()
        os.fsync(note.fileno())
        if not args.quiet:
            print(line, flush=True)
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

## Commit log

2026-10-07 Add hardware design, reverse-engineering tooling, docs, and licensing
    KiCad 10 control board (schematic, PCB, project-local LCSC parts library),
    the bus reverse-engineering toolkit (sniffer/driver scripts + captures) and
    PROTOCOL.md, the LCSC order BOM, and strong-copyleft licensing
    (GPL-3.0 / CERN-OHL-S-2.0 / CC-BY-SA-4.0) with safety/affiliation disclaimer.
    [lcsc_order_bom.csv, scooter_board.kicad_pcb, scooter_board.kicad_sch]
2026-10-07 Add v1 firmware: core ride control (ESP-IDF)
    XIAO ESP32-C3 firmware. One-wire open-drain UART bus driver (colon protocol,
    software echo-filter, 50 Hz poll cadence + 21-byte status decode), throttle/
    brake ADC with filtering/mapping, ride state machine with kick-to-start,
    brake->0 and link-loss interlocks, LEDC buzzer and WS2812 status LED.
    Bench-testable without the scooter. OLED/WiFi/OTA/deep-sleep are later phases.
    [partitions.csv]
2026-10-07 Add NVS config store + ride-feel shaping and configurable lights
    - config.[ch]: versioned NVS-backed settings struct (calibration, ride feel,
    lock/security, lights, IMU, feedback, WiFi/OTA, system) with defaults; the
    web UI will edit g_cfg and call config_save().
    - inputs/control now read g_cfg live (calibration, deadzone, brake threshold).
    - control: throttle cap + curve (linear/progressive) + soft-start slew; new
    RIDE_LOCKED state and a locked inhibit (lock state machine lands next).
    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
2026-10-07 Add gesture detection + lock/security state machine
    - gesture.[ch]: recognise two stationary lever gestures - brake + triple
    throttle blip (lock/unlock toggle) and brake + full throttle held 20 s
    (config/OTA mode entry). Mutually exclusive by construction.
    - security.[ch]: lock state machine. Boots LOCKED; gesture toggles lock/
    unlock; auto-locks after the configured idle timeout while stopped; motion
    alarm while locked (IMU motion input stubbed until the IMU phase).
    - ride loop: wire gesture -> config-mode stub + security -> control lock
    inhibit. Buzzer honours the buzzer_enable config; status LED scales by
    led_brightness and shows the new LOCKED (purple) state.
    Config/OTA entr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
    [board.h, buzzer.c]
2026-10-07 Add IMU wake-on-motion + two-stage deep-sleep power model
    - imu.[ch]: LSM6DS3TR-C over I2C in low-power wake-on-motion mode; INT1
    (open-drain, active-low) for deep-sleep wake, WAKE_UP_SRC polled while awake
    for idle keep-alive and the locked motion alarm. Non-fatal if absent.
    - power.[ch]: stage-2 idle -> deep sleep after auto_sleep_timeout_s. Clears the
    light flags on the controller first (it latches last state once unpolled -
    see PROTOCOL.md 6.4), arms the IMU wake, and esp_deep_sleep_start(); only
    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
2026-10-07 Fix led_strip config for 2.5.x API (led_pixel_format)
    The fetched espressif/led_strip is 2.5.x, which uses led_pixel_format /
    LED_PIXEL_FORMAT_GRB rather than the 3.x color_component_format. Firmware now
    builds clean against ESP-IDF v5.4 (binary ~243 KB, fits the 1.875 MB app slot).
2026-10-07 Add WiFi config portal + web UI + OTA
    - netcfg.[ch]: SoftAP (192.168.4.1) + esp_http_server. Entered by the config
    gesture; serves an embedded single-page UI and a JSON API:
    GET/POST /api/config, GET /api/status, POST /api/ota, POST /api/reboot.
    Auto-exits after config_timeout_s of inactivity.
    - OTA: streams the uploaded .bin to the next OTA slot (esp_ota_*) and reboots.
    - config.[ch]: config_to_json / config_from_json (cJSON) with per-field range
    clamping; the web UI reads and writes the whole config to NVS.
    - web/index.html: schema-driven settings form + OTA upload (progress) + live
    status; no external deps (served on the offline AP). Embedded via EMBED_TXTFILES.
    - app_main: co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
2026-10-07 Add pack-voltage sensing (ADC2, WiFi-gated)
    - inputs: ADC2 (GPIO5) pack read with curve-fitting calibration -> mV, scaled
    by the 470k/33k divider to pack mV. Read only when allowed (ADC2 is blocked
    while the WiFi portal runs); cached otherwise.
    - ride loop samples pack ~1 Hz when WiFi is off; /api/status and the web UI
    now report pack voltage.
2026-10-07 Add guided throttle/brake calibration in the web UI
    - inputs: capture min/max of throttle/brake raw while a calibration session is
    active; expose live raw + captured values.
    - netcfg: /api/cal (GET live values, POST start/apply/cancel). Apply writes the
    captured endpoints to config (with a travel sanity check) and saves.
    - web UI: Start/Apply/Cancel with a live readout - sweep the controls instead of
    typing raw ADC numbers.
2026-10-07 Add OLED telemetry display (SSD1309, LVGL)
    - i2cbus.[ch]: shared I2C master bus; imu.c refactored to use it so the OLED
    and IMU share D4/D5.
    - display.[ch]: SSD1306/09 panel (built into esp_lcd on IDF 5.4) + LVGL via
    esp_lvgl_port. Shows speed (big), SoC, state, current and pack voltage; units
    follow config (km/h / mph). Non-fatal if the OLED is absent.
    - app_main refreshes the display ~5 Hz with a state label.
    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
2026-10-07 Add USB-serial config console (esp_console REPL)
    Interactive console on the native USB-Serial-JTAG, mirroring the web UI by
    reusing the same backend: get / set <key> <value> / status / cal / wifi on|off
    / defaults / reboot. Verified on hardware (set throttle_cap -> saved to NVS ->
    reflected in get).
2026-10-07 Guard OLED/LVGL init behind an I2C presence probe
    Without a panel connected, the LVGL flush task spun on failing I2C writes and
    tripped the task watchdog. display_init now probes 0x3C first and skips the
    panel + LVGL entirely when absent (confirmed on a bare XIAO - no watchdog).
    [display.c]
2026-10-07 Add CI, bring-up checklist, contributing guide, and console docs
    - .github/workflows/firmware.yml: build the firmware (ESP-IDF v5.4, esp32c3) on
    every change under firmware/, upload the .bin as an artifact.
    - firmware/BRINGUP.md: ordered hardware validation checklist for assembled boards.
    - CONTRIBUTING.md: repo layout, build pointer, style, safety, licensing.
    - firmware/README.md: document the USB serial console + web portal config, build
    badge, and update the calibration section.
2026-10-07 Remove firmware kick-to-start (the controller enforces it)
    The motor controller already implements the kick-to-start interlock
    (PROTOCOL.md 6.2) and it cannot be changed, so the firmware mirroring it was
    redundant. control_step now passes the rider's throttle straight through
    (still subject to the brake/lock/link-loss failsafes and curve/cap/soft-start).
    Dropped the kick_to_start config field and bumped CONFIG_VERSION to 2.
2026-10-07 Redesign the config web UI + add favicon
    - Mobile-first restyle: brown theme, status tiles (speed/SoC/current/pack),
    link/lock pills, card sections, toggle switches, sticky save bar, toasts.
    - Embedded emoji favicon (data-URI) + a /favicon.ico 204 handler so browsing
    the portal no longer logs a 404.
    - Dropped the removed kick_to_start field from the form.
2026-10-27 Fix hardware bring-up: bus TX pad, ADC2 pack sense, LED/buzzer bench tools
    - bus: re-attach UART1 TX to the D6 pad after open-drain setup. Applying
    GPIO_MODE_INPUT_OUTPUT_OD to the TX pin detached the UART TX signal from
    the pad, so nothing reached the one-wire bus (tx>0, rx=0, no link).
    Reconnect the TX signal via esp_rom_gpio_connect_out_signal(); the link
    now establishes and frames validate (frames_ok>0).
    - bus: add bus_debug_t counters, bus_get/reset_debug(), bus_selftest_tie()
    (D6<->D7 GPIO continuity test) and echo probes for bring-up diagnosis.
    - sdkconfig: enable CONFIG_ADC_ONESHOT_FORCE_USE_ADC2_ON_C3 so pack voltage
    (D3/ADC2_CH0) reads instead of failing ADC2 one-shot i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
2026-10-27 Fix buzzer: route BZ_DRAIN to footprint pad 2
    The HYG-8503A symbol mapped BZ_DRAIN to pad 3, but the buzzer's - terminal
    is pad 2, so the gate drive never reached the buzzer (scope showed a clean
    2.7 kHz square on the Q1 gate with nothing switching at the buzzer). Swap
    the symbol's lower pin numbers 2<->3 in both the LCSC library and the
    schematic's cached copy so BZ_DRAIN lands on pad 2, then update the PCB
    netlist and re-route the track.
2026-10-27 Add serial input monitor and two-point pack-voltage calibration
    - sercon `mon [secs]`: live 10 Hz stream of throttle/brake (raw, %, the
    gesture HIGH/LOW crossings), brake_active, stationary, and the unlock
    blip counter, so the lock/unlock gesture can be debugged on the bench.
    Backed by inputs_last() (a cached sample, so the console task never
    touches the ADC concurrently) and gesture_get_dbg() (live blip state).
    - Pack voltage: two-point calibration (zero offset + measured span point)
    fitted through (zero_node_mv, 0 V) and (ref_node_mv, measured V), which
    corrects both the divider-ratio error and any ADC offset. Falls back to
    the nominal 470k/33k divider when uncalibrated. New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
2026-10-27 Debounce bus-link loss alerting
    A flapping link re-entered the fault state ~once a second, re-chirping and
    re-logging each time. Track the link transitions directly: chirp and log
    "bus link lost" once on a drop, log "bus link restored after N ms" on
    recovery, and don't re-arm the loss chirp until the link has been solidly
    up for BUS_LINK_ALERT_REARM_US (1 s). The throttle-inhibit failsafe stays
    immediate in control_step(); only the rider chirp and the log are debounced.
2026-10-27 Quiet the board in deep sleep: blank OLED/LED, park buzzer gate
    Before deep sleep the peripherals held their last state: the OLED kept its
    framebuffer lit, the WS2812 latched its last colour, and the buzzer gate
    pad floated (GPIO9 powers down in sleep) so the passive buzzer whined.
    - display_off(): send the SSD1309 display-off command; the framebuffer is
    retained so display_update() restores the readout on wake.
    - status_led_off(): clear the WS2812 so it goes dark in sleep.
    - buzzer_deep_sleep_prep(): leave the Q1 gate (GPIO9) Hi-Z so the external
    1M pulldown (R10) holds it low and Q1 stays off (silent, no 5V ripple fed
    to the buzzer). Not driven high: that turns Q1 on; not held low e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
2026-10-27 Document known hardware notes in BRINGUP
    Faint LDO/MLCC rail whine (normal, not firmware-controllable), the buzzer
    gate on strapping GPIO9 (R9/R10, keep Hi-Z for sleep), WS2812/IMU-INT
    strapping-and-wake sensitivities, and IMU-motion-only deep-sleep wake with
    the imu_wake_sens tuning note. Also note the two-point pack voltage cal.
2026-10-27 Add charging mode: dedicated screen, LED indicator, no deep sleep
    Detect charging from the controller's reported charge current
    (charge_cA >= CHARGE_DETECT_cA; full at soc >= CHARGE_FULL_SOC). While
    charging:
    - Stay awake (never deep sleep while the charger is connected).
    - Spare the OLED: show a decluttered charging screen (big SoC %, charge
    current, CHARGING/FULL) on plug-in and for CHARGE_SCREEN_ON_MS after
    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
2026-10-27 Redesign the OLED UI + light/dark, range, pack smoothing, config migration
    Display:
    - Banded ride screen: state icon (riding/idle/braking/fault/config, plus a
    custom padlock image for locked) + battery/SoC top bar, big centred speed
    (montserrat_36) with the unit beside it, and a current/volts/range footer.
    Pack volts now show one decimal; range shows "--" when there's no link.
    - Charging screen: big centred SoC, an animated filling battery, charge
    current and pack voltage.
    - Light/dark mode via whole-panel colour inversion (display_invert config),
    applied live. Fonts montserrat_12/14/36 enabled; custom lock icon in icons.h
    (generated, A8).
    Firmware:
    - Linear range estimate (rang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
2026-10-27 Add adaptive Ah-based range estimate, screen-off timeout, UI polish
    Range (new range.c/range.h): charge-based (coulomb-counting) remaining-range
    estimate. Learns consumption (Ah/km) by integrating pack current over odometer
    distance while riding, folded into an EMA; range = SoC% x pack_capacity /
    Ah_per_km. SoC comes live from the controller each poll, so storage
    self-discharge can't desync it. Seeded from range_full_km, clamped, outliers
    rejected, persisted to NVS and re-seedable via `range reset`. Shown to 0.1 km
    (~100 m) resolution on the OLED, `status`, and the `range` command.
    Config v6 (append-only migration): wheel_circ_mm, pack_capacity_mah (12.8 Ah
    Bird One pack), display_timeout_s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
2026-10-27 Document active-brake flag bits; refine anti-theft backlog
    PROTOCOL.md: record the two poll-flag bits found by fuzzing (2026-09-14) that
    the stock board never used but the controller honors: 0x02 = cut drive/coast,
    0x04 = active dynamic brake (dissipative, not regenerative - no charge back to
    the pack, braking energy dissipates as heat in the motor windings + controller
    FETs, scaling with speed). Clarify section 6.3: no explicit brake field - the
    brake is never signalled; the ESC infers it from throttle=0 and freewheels. Add
    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
2026-10-27 Document the status LED colours and patterns in the README
    Add a Status LED section: the ride-state colours (red fault, purple locked,
    blue idle, green riding, amber braking) and the special modes that override
    them (cyan config/OTA, breathing amber while charging, solid green when full,
    off in deep sleep). Note that RIDE_READY's colour is defined but not emitted,
    that only charging animates, and that the lock motion alarm is the buzzer, not
    an LED pattern.
2026-10-27 Refresh the firmware README (remove stale content)
    - Status: reflect that it runs on real hardware (bus link + IMU wake confirmed)
    instead of "needs validation"; add rows for the OLED UI, charging mode,
    adaptive range, and screen-off timeout; reframe calibration as per-unit setup.
    - Pin map: complete it (D0 IMU-INT, D3 pack, D4/D5 I2C, D10) and drop the stale
    "used by later phases" note - those are all in use now.
    - Console commands: add mon, bus, range, pack cal, led, beep, gpio; expand the
    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
2026-10-27 Update stale docs: root README firmware status + board.h pin comments
    Root README: the firmware is in firmware/ now, not "not in this repo yet" -
    add it to the repo layout, flip the status line to done (on hardware), and fix
    the note that said it wasn't committed.
    board.h: drop the "(later)" tags on the IMU-INT, pack-sense and I2C pins -
    they're all in use (IMU wake, pack ADC, OLED+IMU on I2C).
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
